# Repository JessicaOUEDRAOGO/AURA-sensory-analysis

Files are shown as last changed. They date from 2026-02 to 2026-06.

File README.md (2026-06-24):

# AURA — Augmented Reality for Sensory Analysis

*Une table de réalité augmentée projective pour observer et enrichir l'analyse des perceptions sensorielles.*

Système de réalité augmentée projective pour l'analyse sensorielle du café (méthode *napping*), développé en stage à Centrale Lyon ENISE / LIRIS avec l'Institut Lyfe. La table suit en temps réel la position de tasses de café et projette directement sur le plateau l'identité de chacune — pendant que les participants évaluent le café sans rien manipuler d'autre que leur tasse.

> Démo vidéo et contexte du projet : [Portfolio](https://jessicaouedraogo.github.io/Portfolio)

<p align="center">
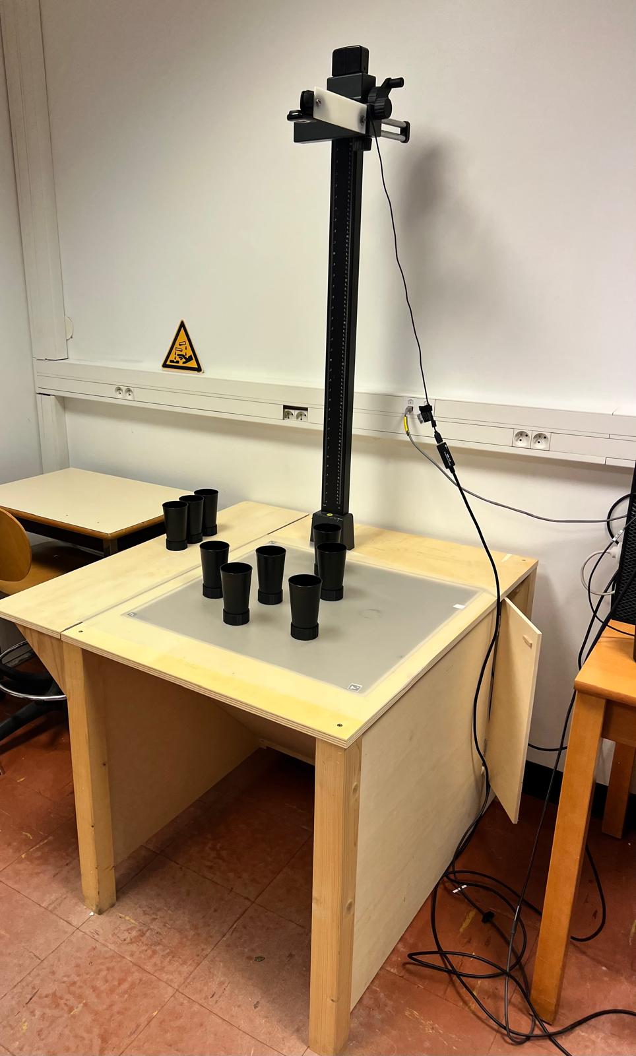
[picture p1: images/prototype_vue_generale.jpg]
Prototype de la table — vue d'ensemble avec les tasses et le rig caméra/projecteur
  
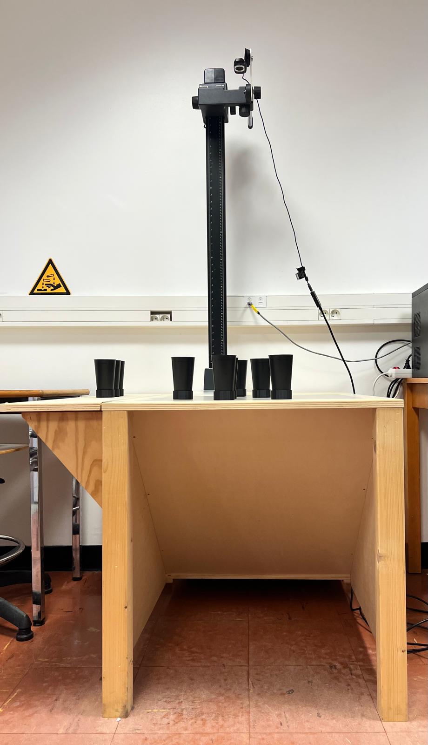
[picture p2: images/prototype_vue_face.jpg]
Prototype de la table — vue de face
  
</p>

**`Python` `OpenCV` `Computer Vision temps réel` `Multithreading` `Filtrage de Kalman` `ArUco` `Fusion de capteurs` `Réalité augmentée projective`**

## En résumé

**Le problème :** suivre 9 tasses strictement identiques en temps réel, sans jamais confondre leur identité — y compris quand on les soulève, qu'on les repose, ou qu'elles se croisent.

**Problématique :** la caméra du dessous détecte les tags ArUco uniquement quand la tasse est posée sur la table. Dès qu'elle est soulevée, le tag n'est plus visible et toute la trajectoire du mouvement est perdue. Pour capturer le mouvement complet, il fallait une deuxième caméra qui voie la tasse lorsqu'elle est levée.

**Ce que j'ai conçu :** l'architecture complète du pipeline — choix et migration des trackers visuels (KCF → MOSSE) sous contrainte de performance (9 tasses à 30 fps), le système d'attribution d'identité tracker↔tag ArUco, et le mécanisme auto-correctif qui détecte et corrige les dérives de tracking en temps réel (5 garde-fous combinés, détaillés plus bas).

**Résultat mesuré :** le système suit chaque tasse sans interruption, posée ou levée, en gardant toujours la bonne identité — y compris quand deux tasses se croisent.

---

## Le problème, version courte

Suivre 9 tasses **strictement identiques** en temps réel, savoir laquelle est laquelle à tout moment — même quand on la soulève, la repose, ou que deux tasses se croisent — sans jamais permuter leurs identités. Voilà le problème. Ce README raconte comment il a été résolu, par itérations successives, chacune révélant le problème suivant.

---

## Itération 1 — une seule caméra ne suffit pas

Le premier prototype reposait uniquement sur une caméra placée sous la table, détectant des tags ArUco collés au fond de chaque tasse. Identité fiable, position précise — mais un trou béant : **dès qu'une tasse est soulevée, le tag sort du champ et toute la trajectoire est perdue.** Pas de données entre le décollage et la repose — exactement le moment le plus intéressant à observer dans un protocole de napping (un participant qui hésite, repose puis re-soulève une tasse).

**→ Il fallait une deuxième source d'information qui continue de voir la tasse même en l'air.**

## Itération 2 — une caméra du dessus, et un nouveau problème : l'identité

Une caméra plongeante (`cam_top`) a été ajoutée pour suivre visuellement chaque tasse par sa silhouette, indépendamment du tag ArUco. Elle ne perd jamais la tasse de vue tant qu'elle reste sur la table ou juste au-dessus.

Mais cette caméra ne voit que des silhouettes — et les 9 tasses sont identiques. Elle peut suivre une forme, pas dire *laquelle*. Il fallait donc associer chaque silhouette suivie à une identité réelle, sans pouvoir s'appuyer sur l'apparence.

**Solution adoptée :** `cam_top` fait le tracking visuel (détection + suivi de boîte englobante), `cam_bottom` reste la source d'identité via ArUco. Un gestionnaire dédié (`CupIdentityManager`) fait le pont entre les deux : il lie un `tracker_id` (purement visuel, sans signification) à un `aruco_id` (l'identité réelle) dès qu'ils sont détectés à proximité l'un de l'autre.

## Itération 3 — deux caméras, deux threads, et un décalage à minimiser

Faire tourner les deux caméras dans le même thread Python s'est avéré quasiment impossible à maintenir en performance : la lecture bloquante d'une caméra (`cap.read()`) gèle l'autre. Chaque caméra tourne donc dans son propre thread.

Mais deux threads indépendants ne tournent jamais à une fréquence parfaitement identique. Mesuré en session réelle :

| Source | Fréquence réelle |
|---|---|
| `cam_top` (boucle principale) | 25 Hz (40 ms/frame) |
| `cam_bottom` (thread ArUco) | ~22 Hz (asynchrone) |

Conséquence directe : au moment où une ligne du CSV est écrite, la position ArUco disponible (`x_bottom`) n'est pas forcément celle de la même frame physique — l'écart peut aller de 0 à ~45 ms. C'est ce qui explique un écart résiduel de position de ~5-15 mm entre `cam_top` et `cam_bottom`, même quand une tasse est parfaitement immobile et que tout fonctionne normalement. Tout l'effort de cette étape a consisté à réduire au maximum cet écart temporel plutôt qu'à l'éliminer complètement (ce qui demanderait une synchronisation matérielle des deux caméras, hors de portée ici).

## Itération 4 — 9 tasses à ~30 fps : KCF est trop lent

Le protocole final exige de suivre jusqu'à 9 tasses simultanément à une cadence proche de 30 fps. Le tracker visuel utilisé jusque-là, **KCF**, coûte environ 8 ms par tasse suivie. Pour 2 tasses, c'est négligeable (16 ms). Pour 9 tasses, ça représente déjà ~72 ms de calcul par frame — largement incompatible avec un budget de ~33-40 ms par frame.

**→ Migration vers MOSSE**, un tracker par corrélation beaucoup plus léger (sous la milliseconde par instance au lieu de 8 ms). Le gain de performance est net — mais MOSSE a une faiblesse connue : il est nettement moins robuste que KCF aux occlusions et aux changements brusques d'apparence.

## Itération 5 — MOSSE perd pied dès qu'il y a collision

Conséquence prévisible du passage à MOSSE : dès que deux tasses se croisent ou se touchent, le tracker peut décrocher de sa cible — soit il la perd complètement, soit, pire, il **s'accroche à la tasse voisine** en silence, sans jamais signaler d'erreur. Sans garde-fou, ce genre de glissement produit un tracker qui continue de répondre, mais qui ment sur la position réelle de la tasse.

**→ Construction d'un système auto-correctif**, qui ne fait pas confiance à un tracker juste parce qu'il répond. Il croise systématiquement deux sources d'information :

1. **Re-détection périodique** (toutes les ~150 ms, soit 1 frame sur 4) : un masque binaire redétecte les silhouettes de tasses sur l'image et tente de réassocier chaque tracker à la détection la plus proche, le réinitialisant si besoin.
2. **Contrainte de taille de boîte** (`BBOX_GROW_RATIO`) : si la boîte suivie par MOSSE grossit anormalement (signe classique d'un tracker qui a perdu sa cible et suit une zone floue plus large), le tracker est invalidé immédiatement plutôt que de continuer à publier une position fausse.
3. **Vérification croisée avec l'ArUco** (`check_aruco_drift`) : tant qu'un tracker est lié à un tag, sa position est comparée en continu à la position ArUco réelle de la même tasse. Si l'écart dépasse un seuil pendant plusieurs frames consécutives, c'est la preuve que le tracker a glissé sur une autre tasse — il est invalidé, et les frames déjà écrites dans le CSV pendant la dérive sont **marquées rétroactivement comme suspectes** (colonne qualité), plutôt que silencieusement laissées telles quelles.
4. **Récupération des tags orphelins** (bootstrap) : si un tag ArUco reste détecté sans aucun tracker associé pendant un certain temps (tasse repérée mais jamais reliée à un suivi visuel), un nouveau tracker est spawné automatiquement à la position corrigée, avec une zone d'exclusion autour des autres tags connus pour éviter une mauvaise association, puis validé sur plusieurs frames avant confirmation.
5. **Anti-scintillement** : les tags ArUco clignotent naturellement (détectés/perdus en alternance, normal à ~22 Hz). Sans filtrage, ça produirait des cycles `AIRBORNE ↔ MATCHED` plusieurs fois par seconde. Une repose n'est donc confirmée qu'après 3 détections stables consécutives.

---

## Architecture résultante

```
cam_top (MOSSE, 25 Hz) ──┐
                          ├──► CupIdentityManager ──► Projecteur (anneaux + identité)
cam_bottom (ArUco, ~22Hz)┘         (PENDING / MATCHED /        └──► CSV + JSON
                                     AIRBORNE / LOST)
```

| État | Signification |
|---|---|
| `PENDING` | Tag vu, pas encore de tracker associé |
| `MATCHED` | Tracker et tag liés et cohérents |
| `AIRBORNE` | Tasse soulevée — tag invisible, tracker continue seul |
| `LOST` | Tracker perdu, tag invisible depuis trop longtemps |

---

## Deux filtres pour deux usages différents

La position brute (`x_raw`) est temporellement exacte, avec un bruit de mesure faible — largement suffisant pour l'analyse. Mais ce bruit change de direction à chaque frame : projeté à l'écran, ce tremblement frame-à-frame est visible à l'œil même si l'écart réel est minime.

**EMA** lisse ce tremblement pour la projection des cercles, en moyennant les positions récentes. Sa limite : ce lissage introduit un décalage temporel — la position affichée correspond à où était la tasse quelques dizaines de millisecondes plus tôt. Invisible à l'œil sur la projection, mais ça rend l'EMA inutilisable pour l'analyse de trajectoire — il n'est donc utilisé que pour l'affichage.

**Kalman** est utilisé pour l'export CSV. Plutôt que de moyenner le passé comme l'EMA, il modélise aussi la vitesse de la tasse pour prédire sa position — ce qui lisse le bruit sans réintroduire le même décalage temporel. C'est la colonne `x_filtered`/`y_filtered` à utiliser pour toute analyse de trajectoire.

---

## Données exportées

Chaque session produit :

- **`{session}.csv`** — une ligne par frame, 4 sources de position par tasse (`_raw`, `_ema`, `_filtered`, `_bottom`) + une colonne de qualité (0=OK, 1=hijack détecté, 2=airborne, 3=bootstrap en validation, 4=lost).
- **`{session}_trackers_raw.csv`** — une ligne par tracker actif par frame, sans aucune perte, même avant association à un tag.
- **`{session}_associations.json`** — historique complet des liaisons/déliaisons tracker↔tag (bind, unbind, hijack), avec frame et horodatage.
- **`{session}.mp4`** — enregistrement vidéo `cam_top`.

**Pour une analyse post-session :** utiliser `x_filtered`/`y_filtered` (Kalman) comme position de référence, indexer par `aruco_id` (jamais `tracker_id`, qui change à chaque rebind), filtrer sur `state = MATCHED` pour les phases de contact avec la table, et garder `x_raw` comme contrôle qualité.

---

## Analyser les trajectoires (`plot_trajectory.py`)

Un CSV brut de session n'est pas lisible directement — il faut un outil pour visualiser les trajectoires et vérifier que le tracking est cohérent avant d'analyser quoi que ce soit.

`plot_trajectory.py` charge un CSV de session et trace, pour une ou plusieurs tasses, la trajectoire choisie parmi les 4 sources (`raw`, `ema`, `filtered`, `bottom`). Quelques points utiles :

- **Filtrage automatique des frames non fiables** — les frames marquées `hijack` (tracker sur la mauvaise tasse) ou `lost` sont retirées avant le tracé, pour ne pas afficher une trajectoire fausse comme si elle était valide.
- **Pas de trait fantôme sur les trous de données** — quand le tracking est interrompu plus de 8 frames (tasse perdue, hors champ), la trajectoire est coupée en segments plutôt que reliée par une ligne droite qui n'a jamais existé.
- **Flèches de direction + repères temporels (t1…t8)** — un tracé de trajectoire seul ne montre pas le sens du déplacement ni l'ordre chronologique ; ces repères permettent de lire "la tasse est passée par ici, puis par là" sans deviner.
- **Superposition de la trajectoire ArUco (`bottom`)** en surbrillance sous la courbe principale — les zones où elle est dense correspondent aux moments où la tasse était posée et détectée ; les zones vides correspondent aux phases de mouvement ou de occlusion.
- **Vue "expérimentateur"** — rotation à 180° des coordonnées pour afficher la trajectoire du point de vue de la personne assise face à la table, plutôt que du point de vue de la caméra du dessous.
- **Contrôle qualité intégré** — l'outil recalcule l'écart résiduel médian entre `ema` et `bottom` pour chaque tasse et signale en console si un écart dépasse 5 mm, pour repérer directement une dérive de calibration ou de synchronisation au lieu de la découvrir à l'œil sur le graphique.

---

## Limites connues

Un écart de position (jusqu'à ~1,5 cm) subsiste entre `cam_top` et `cam_bottom` pour une même tasse. Il augmente avec la vitesse, surtout en trajectoire curviligne — donc lié à la désynchronisation des deux caméras (25Hz vs ~22Hz, deux threads indépendants).

---

## Installation

```bash
conda create -n ra_clean python=3.11
conda activate ra_clean
pip install opencv-contrib-python numpy PyQt6
```

⚠️ `opencv-contrib-python` est obligatoire (pas `opencv-python`) — `cv2.aruco` et `cv2.legacy.TrackerMOSSE_create()` n'existent que dans le build contrib.

Sous Windows, désactiver la **suspension sélective USB** sur les ports caméra (Gestionnaire de périphériques → Concentrateur USB → Gestion de l'alimentation) : sans ça, `cam_top` subit des coupures aléatoires — un problème matériel/OS, pas logiciel.

## Lancement

```bash
python napping_lite.py
```

Lancement interactif (nom du protocole, ID participant, projection on/off). Sorties écrites dans `data/sessions/lite/`.

| Touche | Action |
|---|---|
| `q` | Quitter |
| `r` | Reset complet des trackers |
| `+` / `-` | Ajuster le seuil de détection |
| `c` | Activer/désactiver la correction 3D |
| `i` | Résumé de debug des identités |
| `p` | Activer/désactiver la projection |

---

## Stack technique

Python 3.11 · OpenCV (contrib) · NumPy · PyQt6 · ArUco (`DICT_4X4_50`) · Filtrage EMA + Kalman (modèle vitesse constante)

---

Développé par Jessica Ouedraogo — double diplôme ingénieur électromécanique (ENSAM Meknès) / M2 Technologies 3D Interactives (Arts et Métiers Chalon-sur-Saône).

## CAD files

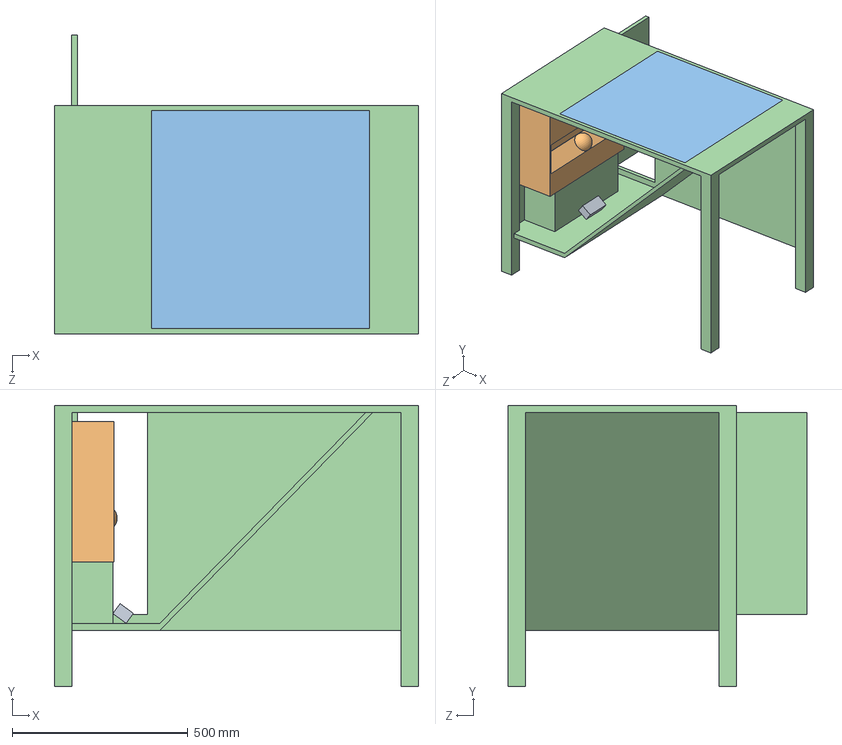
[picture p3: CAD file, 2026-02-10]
3D_Solidworks/Assemblage/Final-Assemblage Final 60x60_marge.SLDASM
1036.0 x 800.0 x 850.0 mm
Final-TableV3 60x60_marge_80_haut
60x60_plateau
eh-ls650-noir
webcam MX Brio Logi

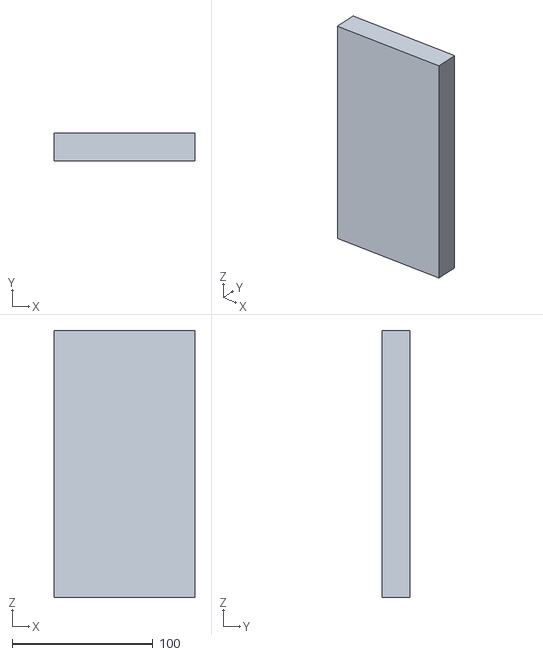
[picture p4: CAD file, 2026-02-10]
3D_Solidworks/pièce impression 3D/Cale Vidéo Projecteur.STL
100.0 x 20.0 x 190.0

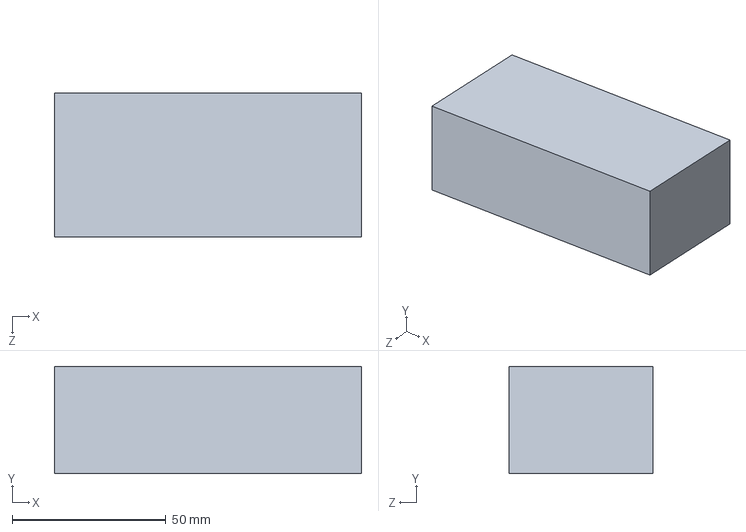
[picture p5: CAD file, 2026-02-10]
3D_Solidworks/pièce/webcam MX Brio Logi.SLDPRT
100.0 x 35.0 x 47.0 mm

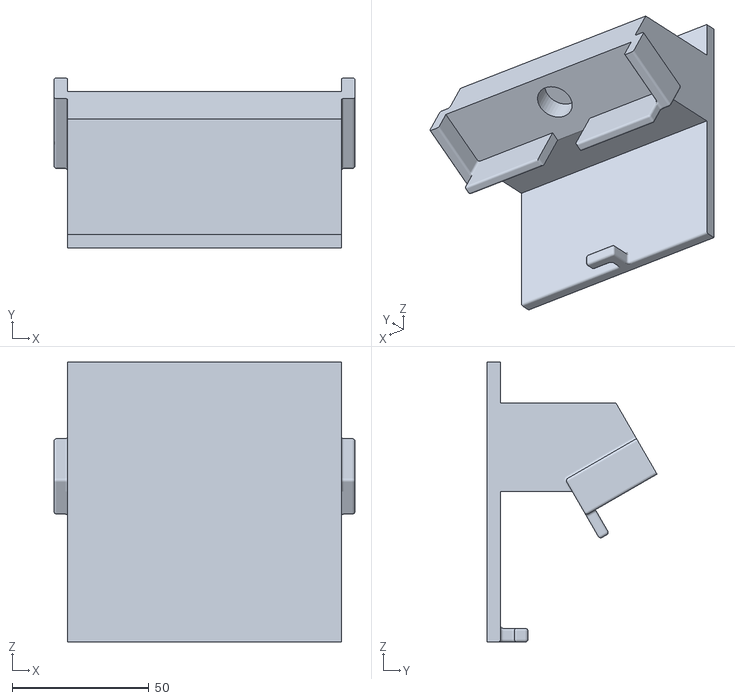
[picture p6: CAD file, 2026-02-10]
3D_Solidworks/pièce impression 3D/Support Webcam.STL
110.0 x 62.2 x 102.3

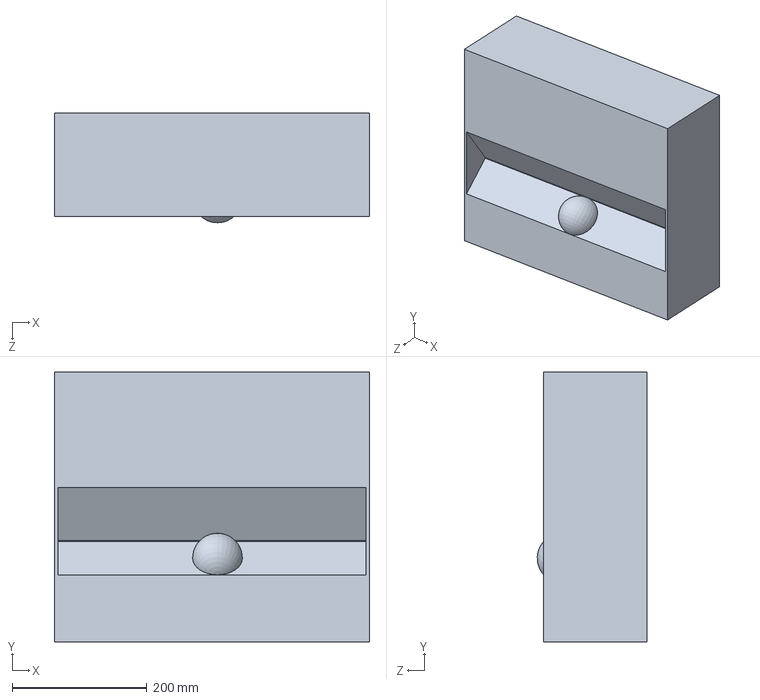
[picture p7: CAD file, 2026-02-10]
3D_Solidworks/pièce/eh-ls650-noir.SLDPRT
467.0 x 400.0 x 162.5 mm

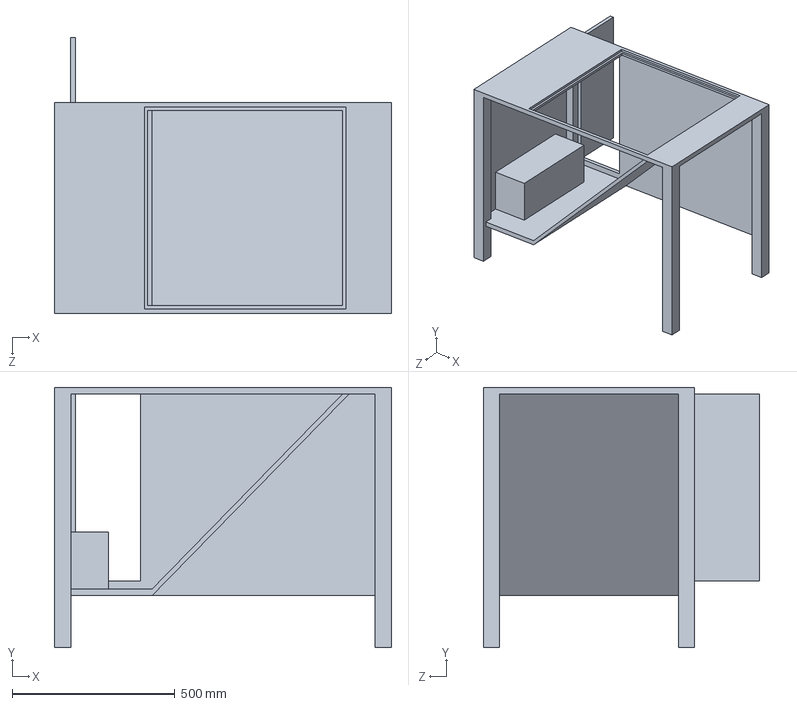
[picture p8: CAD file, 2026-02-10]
3D_Solidworks/pièce/Final-TableV3 60x60_marge_80_haut.SLDPRT
1036.0 x 800.0 x 850.0 mm

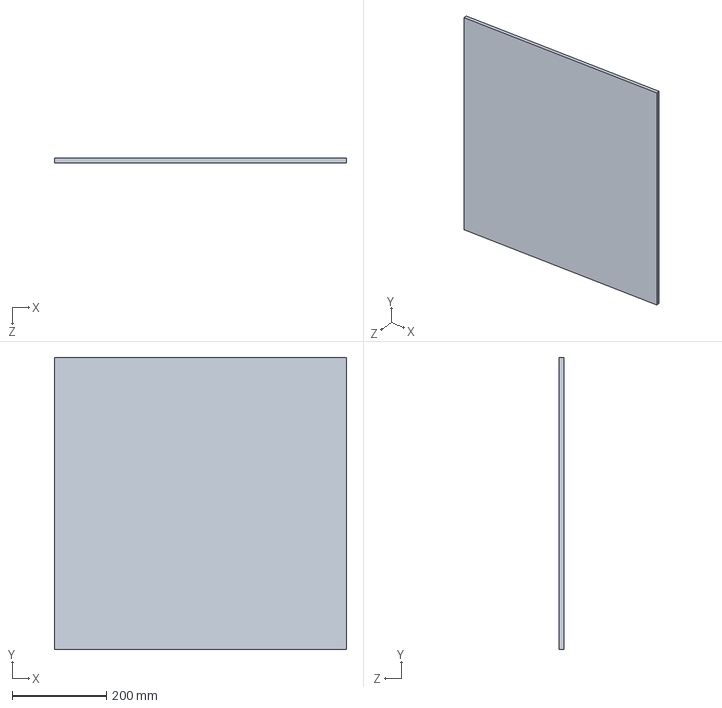
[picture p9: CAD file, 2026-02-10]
3D_Solidworks/pièce/60x60_plateau.SLDPRT
620.0 x 620.0 x 10.0 mm

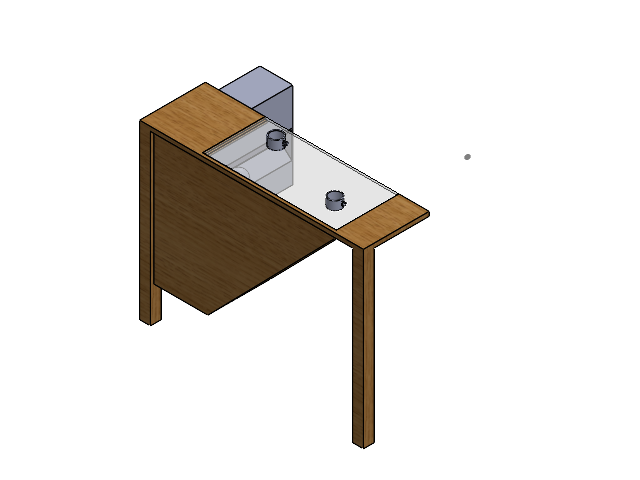
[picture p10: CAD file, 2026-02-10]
3D_Solidworks/Assemblage/CutAssemblageAssemblage1.SLDASM
cut Final-TableV3 60x60_marge_80_haut
eh-ls650-noir
webcam MX Brio Logi
Support Webcam
cut60x60_plateau
CUP x 2

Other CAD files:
3D_Solidworks/pièce/Support Webcam.SLDPRT
3D_Solidworks/pièce/Support Vidéo Projecteur.SLDPRT

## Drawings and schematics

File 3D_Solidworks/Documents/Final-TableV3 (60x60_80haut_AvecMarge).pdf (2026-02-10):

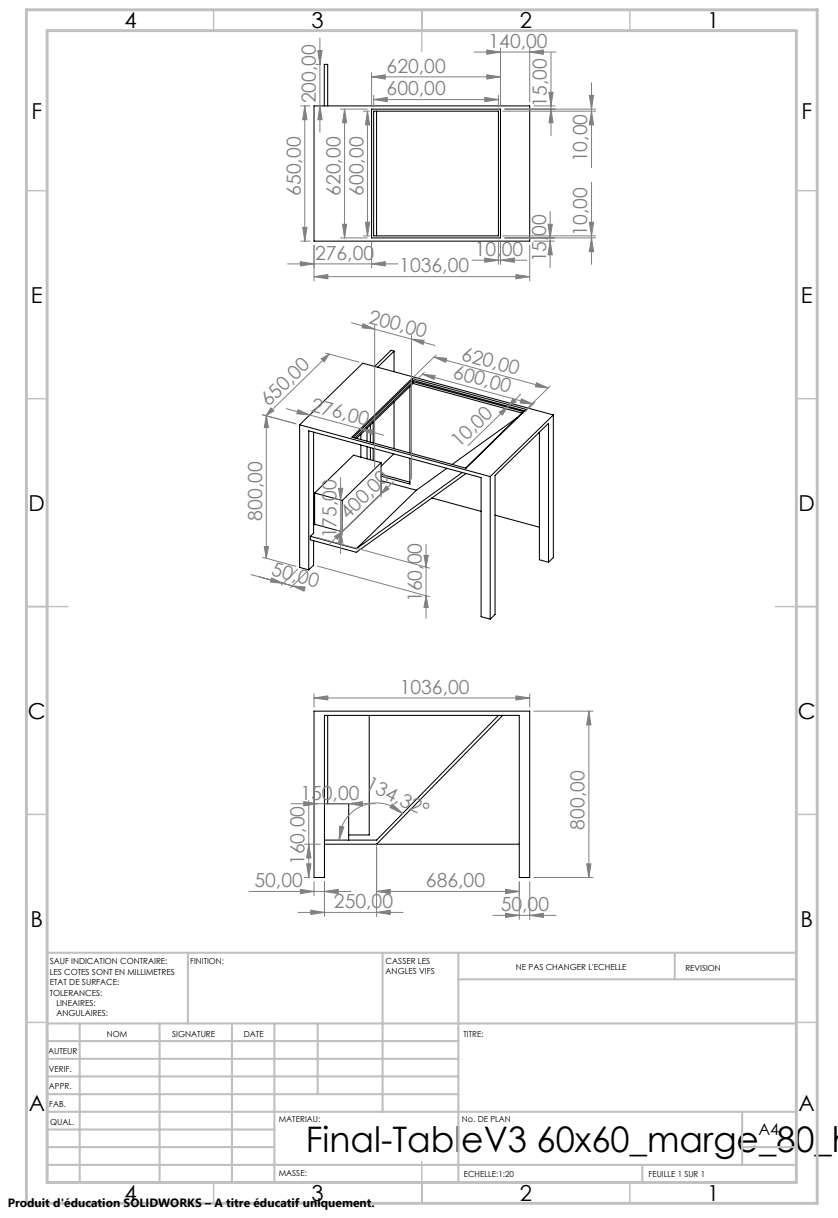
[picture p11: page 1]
FINITION:; CASSER LES; ANGLES VIFS; NE PAS CHANGER L'ECHELLE; REVISION; ECHELLE:1:20; FEUILLE 1 SUR 1; Final-TableV3 60x60_marge_80_haut

SAUF INDICATION CONTRAIRE:
LES COTES SONT EN MILLIMETRES
ETAT DE SURFACE:
TOLERANCES:
LINEAIRES:
ANGULAIRES:

NOM | SIGNATURE | DATE | | | | TITRE:

AUTEUR
VERIF.
APPR.
FAB.
QUAL. | | | | MATERIAU: | No. DE PLAN | A4

Produit d'éducation SOLIDWORKS – A titre éducatif uniquement.

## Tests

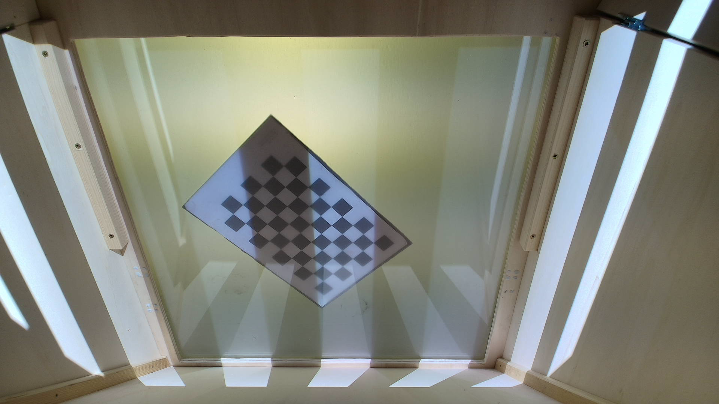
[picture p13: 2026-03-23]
NappingAnalysisGUI/src/core/calibration/scripts_non_essential/projector_calibration_data/pose_screen_08/camera_captures/capture_008.png

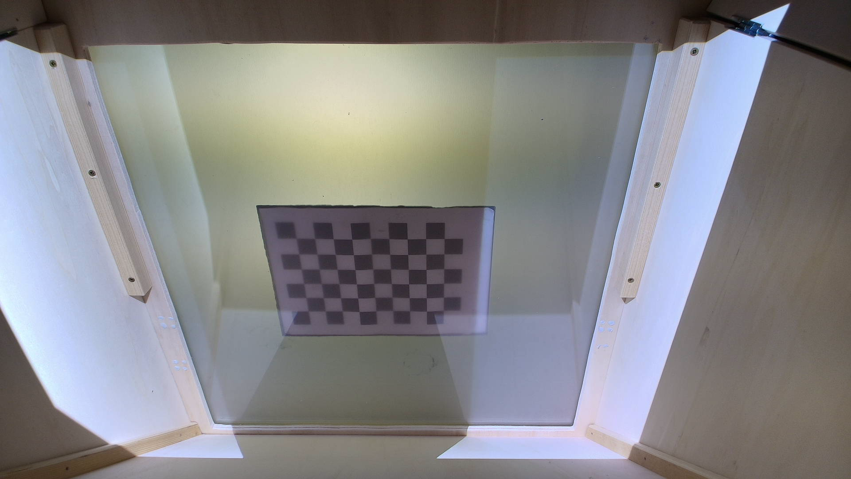
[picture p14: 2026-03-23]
NappingAnalysisGUI/src/core/calibration/projector_calibration_data/pose_screen_03/camera_captures/capture_004.png

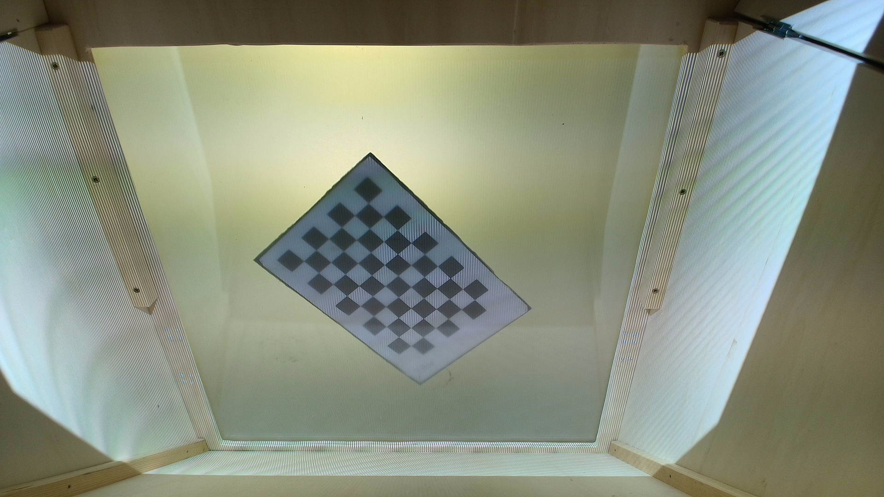
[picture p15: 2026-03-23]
NappingAnalysisGUI/src/core/calibration/projector_calibration_data/pose_screen_04/camera_captures/capture_020.png

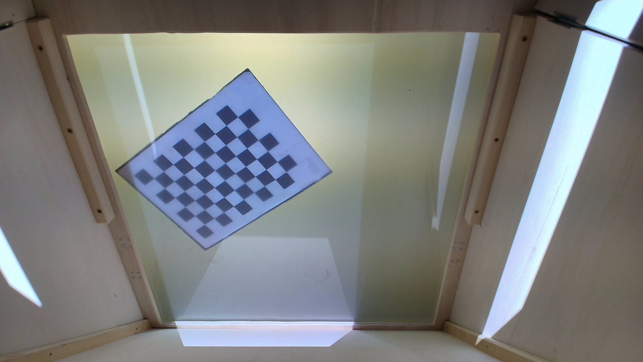
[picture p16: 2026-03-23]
NappingAnalysisGUI/src/core/calibration/projector_calibration_data/pose_screen_12/camera_captures/capture_005.png

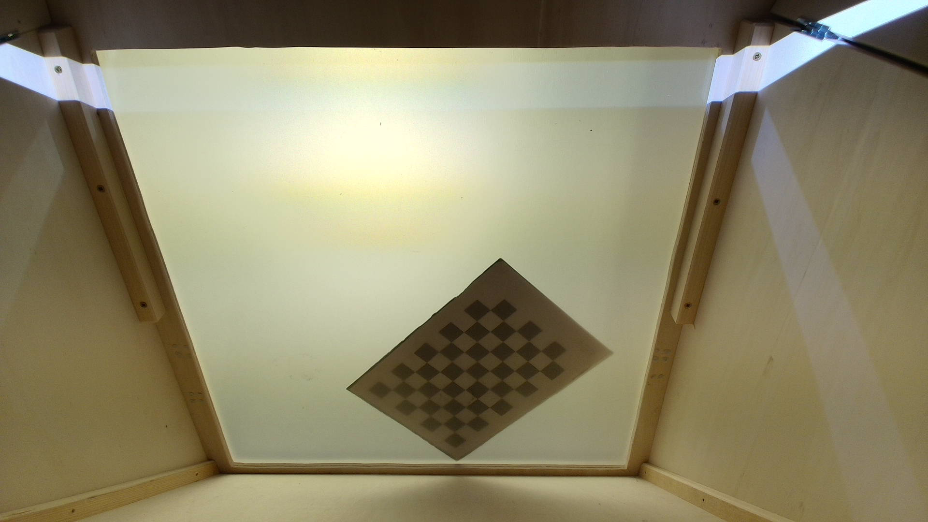
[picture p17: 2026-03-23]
NappingAnalysisGUI/src/core/calibration/projector_calibration_data/pose_screen_11/camera_captures/capture_024.png

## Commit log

2026-02-10 resolution du probleme de camera
2026-02-11 correction de la projection_maintenant_ok
    [data_10-02-2026_13h-41m-38s.csv, data_10-02-2026_13h-46m-38s.csv, data_10-02-2026_13h-54m-04s.csv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]
2026-02-11 prise en compte des tags 0 à 49
    [data_10-02-2026_13h-41m-38s.csv, data_10-02-2026_13h-46m-38s.csv, data_10-02-2026_13h-54m-04s.csv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]
2026-02-11 fix de la grille d'affichage coordonnées x y
2026-02-11 fix des petits bugs_version0 ok
    [data_11-02-2026_14h-39m-33s.csv, data_11-02-2026_14h-44m-44s.csv, data_11-02-2026_14h-45m-29s.csv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]
2026-02-13 Stop tracking local calibration_data.json
2026-02-16 Clean export of files (protocol, sessions)
    [data_11-02-2026_14h-26m-51s.csv, data_11-02-2026_14h-39m-33s.csv, data_11-02-2026_14h-44m-44s.csv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]
2026-02-17 Step3 Timeline stable: fix freeze on stop, fix overlay module, fix projection loop, thread cleanup
2026-02-18 the video is at the center_The buttons are not visible but they are working
2026-02-18 the video is at the center_The buttons are visible and they are working GREAT
2026-02-18 projection background design needed ajustements color of button
2026-03-13 Calibration pipeline: camera calibration, projector calibration, stereo calibration and screen pose estimation
2026-03-17 la consigne s'affiche bien du coté utilisateur effet miroir corrigé mais overlay décalé parfois consigne tronquée
2026-03-17 la consigne s'affiche bien du coté utilisateur effet miroir corrigé mais overlay corrigé mais consigne tronquée
2026-03-17 la consigne s'affiche bien du coté utilisateur effet miroir corrigé mais overlay corrigé mais consigne n'est plus tronquée mais leger vide à gauche et en haut
2026-03-24 ajout des images de detection du damier
2026-03-24 correction du miroir au niveau de la grille sur l'interface
2026-03-24 tentative de corriger décalage des cercles
2026-03-24 tentative de corriger décalage des cercles2
2026-03-25 pose_aruco automatique sur 120 frame
2026-03-25 erreur de reprojection la plus faible 0.02
2026-03-26 nettoyage des scripts et ajout d'une correcton pour la distorsion
2026-03-29 verification de la calibration
2026-03-30 ajout point rouge au lieu de carré vert
2026-03-31 suppression de la logique de correction de H
2026-03-31 verification de Hgraph et Hproj le problème de décalage ne vient pas de là
2026-03-31 verification du projecteur uniquement je vois que le point central n'est pas bon (indépendamment de la calibration et de la caméera
2026-03-31 Détermination de la surface utile du projecteur
2026-04-09 version V2 presque stable : on a le decalage mais il est minim
2026-04-10 Add camera_top calibration (npy + json) + cleanup images
2026-04-10 Ignore calibration images and generated files
2026-04-13 pose de la camera_top
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2026-04-13 coins en fonction de cam_top
2026-04-14 correction de la pose et validation de H pixel vers mm
2026-04-15 on passe a pose 3D vers 2D a cause de Z diff de 0
2026-04-16 dtection de la main extraction de mean pouce index majeur
2026-04-20 pb de retour propre au terminal quand on quitte l'app mais pas de freeze
2026-04-20 amelioration du suivi de la tasse moins de latence
2026-04-21 changement methode de pose camera_bottom_= methode cam_top
2026-04-21 changement methode de pose camera_bottom_= methode cam_top tentative
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2026-04-24 nettoyage interne des scripts
2026-04-24 suppression des fichiers json inutilisé
2026-04-27 point rouge de top_cam dans grille
2026-04-27 amelioration de la logique couleur orange pour peut etre soulevée
2026-04-29 petite amélioration tracking mais presence de collision
2026-04-30 tentative de correction
2026-05-04 mise en place de la logique tracker CSRT
2026-05-06 tracker s'attache à d'autre tasse
2026-05-07 Nettoyage en profondeur et creation de thread pour cam top, cam bottom et projection
2026-05-07 succes du demarrage de la cam top
2026-05-07 changement orientation de la camera
2026-05-07 changement orientation de la camera2
2026-05-07 homographie pour passer de cam top a cam_bottom
2026-05-11 amélioration tracking des tasses
2026-05-11 amélioration du point de détection
2026-05-11 ajout d'une memoire persistante pour gérer le cas de l'occlusion
2026-05-11 tracking fonctionne plus de fusion main tasse persistance de l'id mais il ne faut pas que la tasse passe au dessus d'une autre.
2026-05-11 correction de la hauteur de la tasse.
2026-05-11 tracking en continue des tasses par cam_top
2026-05-13 plus de cercles fantomes, projection fluide sans saccades
2026-05-13 Ajout d'un script analyse des trajectoires
    [RA_napping_a_20260513_100015.csv]
2026-05-13 Ajout de la fonctionalité choix du cup
    [1.csv]
2026-05-13 algo pour analyser les trajectoires ok
2026-05-13 ajout de l'enregistrement de la video pour tracking des mains
    [hand_tracking_on.csv]
2026-05-19 lancement de l'optimisation temps de calcul
2026-05-19 Avant remap puis resize maintenant resize et ensuite remap gain de fps
2026-05-19 Thread dédié a la camera top
2026-05-19 purge pour éviter la fluide de données
2026-05-19 tentative de correction de la chute de fps pour le test
2026-05-19 correction plus de chute de fps version 1.0 appli lite
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2026-05-19 esthétique de la grille à améliorer, tracking id a améliorer
2026-05-19 améliorer la robustesse et écriture prope dans le csv
2026-05-19 esthétique de la grille ameliorée
2026-05-20 enrichissement du csv: coordonnées de top, bottom, tracker, ajoutées et aussi les états : pending, unmatch, match
2026-05-21 Mesure du lag avec les differents filtre; ajout de filtre kalman pour compenser le décalage de ema pour le csv
    [filtre.csv, session.csv]
2026-05-21 Mesure du delay_ms entre top et bottom
    [D.csv]
2026-05-21 retour au csv sans timestamp de bottom
2026-05-21 ajout dans gitignore
    [D.csv]
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2026-05-26 plus de collisions et saut de trackers avec Mosse
2026-05-26 nettoyage: suppression des csv
    [1.csv, RA_napping_a_20260513_100015.csv, filtre.csv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]
2026-05-28 Changement de position physique du setup (recalibartion et pose totalement refaite
2026-05-29 petit nettoyage externe modification des noms de fichiers
2026-06-01 gestion de la collision
2026-06-01 gestion de la collision2 ajout d'une colonne pour voir l'etat de collision
2026-06-01 script analyse des trajectoires
2026-06-01 script analyse des trajectoires1
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2026-06-03 gestion correcte des occlusins
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2026-06-03 ajout des etats dans le script analyse des trajectoires
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2026-06-03 ajout de l'option vue expérimentateur correcte
2026-06-03 option pose uniquement valable pour raw, filtered et emma
2026-06-04 correction offset appliqué sur raw, filtered,ema
2026-06-08 deplacement de la table vers un autre bureau recalibration complète ok
2026-06-22 Update README with details on EMA and Kalman filters
    Clarify the usage and performance of EMA and Kalman filters in the README.
2026-06-22 Revise filter descriptions in README.md
    Updated explanations for EMA and Kalman filters in the README.
2026-06-22 Fix formatting in README for camera position discrepancy
2026-06-24 Revise position discrepancy details in README
    Updated the explanation of the position discrepancy between `cam_top` and `cam_bottom`, reducing the residual position error from ~15-20 mm to ~5-15 mm. Adjusted the known limits section to reflect the increased position discrepancy of up to ~1.5 cm.
